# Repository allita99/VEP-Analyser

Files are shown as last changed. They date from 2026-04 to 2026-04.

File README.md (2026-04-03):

# VEP-Analyser-Motherboard

This repository contains an updated version of the hardware and software developed during my Bachelor's thesis, with incremental improvements and ongoing refinements.

The project integrates multiple components required for a VEP-based system, including firmware, sensor hardware, and the main motherboard design.

---

## Contents

* **Microcontroller Code**
  Firmware used for signal acquisition, control, and system interaction.

* **Motherboard Design**
  Central hardware platform responsible for system integration, power distribution, and communication between components.

* **VEP Sensor (VEPsor) Design**
  Hardware for acquiring visual evoked potential signals.

---

## Status

This repository reflects a working but evolving system:

* Several design and implementation improvements have been applied compared to the original thesis version
* Some components are still under development or require further validation
* Minor inconsistencies or unfinished elements may remain

---

## Purpose

The project is intended for:

* Research and experimentation in Brain-Computer Interfaces (BCI)
* Development and testing of VEP-based acquisition systems
* Educational use and hardware/software prototyping

---

## Notes

* Hardware designs may require verification before fabrication
* Firmware may need adaptation depending on the specific setup
* Some features are still work in progress and subject to change

---

Acknowledgement

Parts of the documentation and written content in this repository were generated with the assistance of AI tools. The text may be revised in the future if inaccuracies, inconsistencies, or improvements are identified.

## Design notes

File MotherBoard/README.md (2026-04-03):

# VEPsor – Motherboard Hardware

The **VEPsor Motherboard** is the central hardware component of the VEP Analyzer project. It functions as the primary interface between VEP sensor modules, processing units, and external systems, enabling reliable data acquisition and seamless system integration.

This repository contains all resources required to review, manufacture, and assemble the motherboard.

---

## Preview

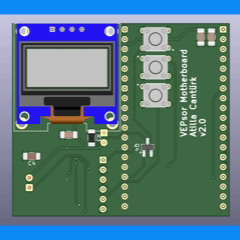
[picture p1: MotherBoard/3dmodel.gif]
3D Model


---

## Repository Contents

- **KiCad Project Files**  
  Complete schematic and PCB layout files for modification and extension.

- **Bill of Materials (BOM)**  
  Comprehensive list of components required for assembly.

- **Gerber Files**  
  Manufacturing-ready files for PCB fabrication.

- **schematics.pdf**  
  Exported schematic for quick inspection of the circuit design.

---

## Overview

The motherboard is designed to:

- Interface with VEP sensor modules  
- Provide stable power distribution across the system  
- Enable communication between hardware components  
- Serve as a reliable platform for BCI system integration  

### Key Design Goals

- Modular integration with sensor units  
- Robust signal routing and power management  
- Use of standard, widely available components  
- Expandability for future system extensions  

---

## Getting Started

### 1. Review the Design
- Open the KiCad project files for full access to the design  
- Use `schematics.pdf` for a quick overview  

### 2. PCB Fabrication
- Upload the Gerber files to a PCB manufacturer (e.g., JLCPCB, PCBWay)

### 3. Component Sourcing
- Use the BOM to procure all required components  

### 4. Assembly
- Assemble the board according to the PCB layout and schematic  
- Verify all power rails and connections before powering the system  

---

## Notes

- Ensure proper handling of power distribution sections  
- Follow ESD safety procedures during assembly  
- Validate voltage levels before connecting sensor modules  

---

## Intended Use

This hardware is intended for:

- Research and development in BCI systems  
- Integration of VEP-based sensing platforms  
- Experimental signal acquisition and processing setups  

This system is **not intended for medical or clinical use**.

---

## Feedback and Contributions

Feedback is encouraged. If you identify a bug, design issue, documentation error, or have suggestions for improvement, please open an Issue.

Constructive comments and contributions are welcome.

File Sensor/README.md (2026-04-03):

# VEPsor – VEP Sensor Hardware

**VEPsor (VEP Sensor)** is the hardware acquisition component of the VEP Analyzer project. It provides a compact and reproducible platform for capturing visual evoked potentials (VEPs) in Brain-Computer Interface (BCI) applications.

This repository contains all resources required to review, manufacture, and assemble the hardware.

---

## Preview

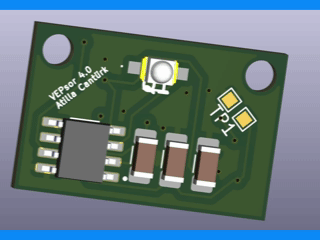
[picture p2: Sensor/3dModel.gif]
3D Model


---

## Repository Contents

- **KiCad Project Files**  
  Complete schematic and PCB design files for editing and modification.

- **Bill of Materials (BOM)**  
  Comprehensive list of components required for assembly.

- **Gerber Files**  
  Manufacturing-ready files for PCB fabrication.

- **schematics.pdf**  
  Exported schematic for quick inspection and validation of the circuit design.

---

## Overview

The VEPsor board is designed for:

- Acquisition of EEG signals related to visual stimuli  
- Integration into BCI systems  
- Rapid prototyping and experimental validation  

### Key Design Goals

- Reproducibility  
- Use of accessible, standard components  
- Compatibility with common EEG acquisition workflows  

---

## Getting Started

### 1. Review the Design
- Open the KiCad project files for full access to schematics and layout  
- Alternatively, inspect `schematics.pdf` for a quick overview  

### 2. PCB Fabrication
- Upload the Gerber files to a PCB manufacturer (e.g., JLCPCB, PCBWay)

### 3. Component Sourcing
- Use the BOM to order all required components  

### 4. Assembly
- Assemble the PCB according to the schematic and layout  
- Verify all connections before powering the board  

---

## Notes

- Handle analog and sensitive components with care  
- Follow ESD protection practices during assembly  
- Verify power supply requirements before operation  

---

## Intended Use

This hardware is intended for:

- Research and educational purposes  
- Experimental BCI systems  
- VEP signal acquisition and analysis  

This system is **not intended for medical or clinical use**.

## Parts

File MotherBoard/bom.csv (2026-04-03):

Designator | Footprint | Quantity | Value | LCSC Part #
C1, C10, C2, C3, C4, C5, C7 | 1206 | 7 | C_Small
C6 | 1206 | 1 | 1.5nC
C8 | 1206 | 1 | 0.22uC
D1 | LED_D5.0mm | 1 | LED
J2, J4 | PRT16766 | 2 | PRT-16766
J3 | PinHeader_1x06_P2.54mm_Vertical | 1 | Conn_01x06_Pin
LED1 | LED_D5.0mm | 1 | PT334-6C
Q4 | SOT-23_Handsoldering | 1 | NMOS
R10 | 1206 | 1 | 22kR
R11, R12 | 1206 | 2 | 220kR
R3 | 1206 | 1 | 250R
R8 | 1206 | 1 | 1MR
R9 | 1206 | 1 | 100kR
S1, S2, S3 | FSM4JH | 3 | FSM2JH
U1 | ESPRESSIF_ESP32-DEVKITC-32UE | 1 | ESP32-DEVKITC-32UE
U2 | MODULE_DM-OLED096-636 | 1 | DM-OLED096-636
U3 | SOIC127P600X175-8N | 1 | MCP6002-I_SN

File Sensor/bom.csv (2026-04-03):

Designator | Footprint | Quantity | Value | LCSC Part #
C1 | 1206 | 1 | 1.5nC
C2, C3 | 1206 | 2 | 0.22uC
D1 | SOD3716X135N | 1 | D_Schottky
J1 | SolderJumper-3_P1.3mm_Open_RoundedPad1.0x1.5mm_NumberLabels | 1 | Conn_01x03_Pin
J2 | PRT16766 | 1 | PRT-16766
Q1 | APDA3020P3CP22 | 1 | APDA3020P3C-P22
R1 | 1206 | 1 | 1MR
R2, R5 | 1206 | 2 | 220kR
R3 | 1206 | 1 | 22kR
R4 | 1206 | 1 | 100kR
TP1 | TestPoint_Pad_1.0x1.0mm | 1 | TH Testpoint
U2 | SOIC127P600X175-8N | 1 | MCP6002-I_SN

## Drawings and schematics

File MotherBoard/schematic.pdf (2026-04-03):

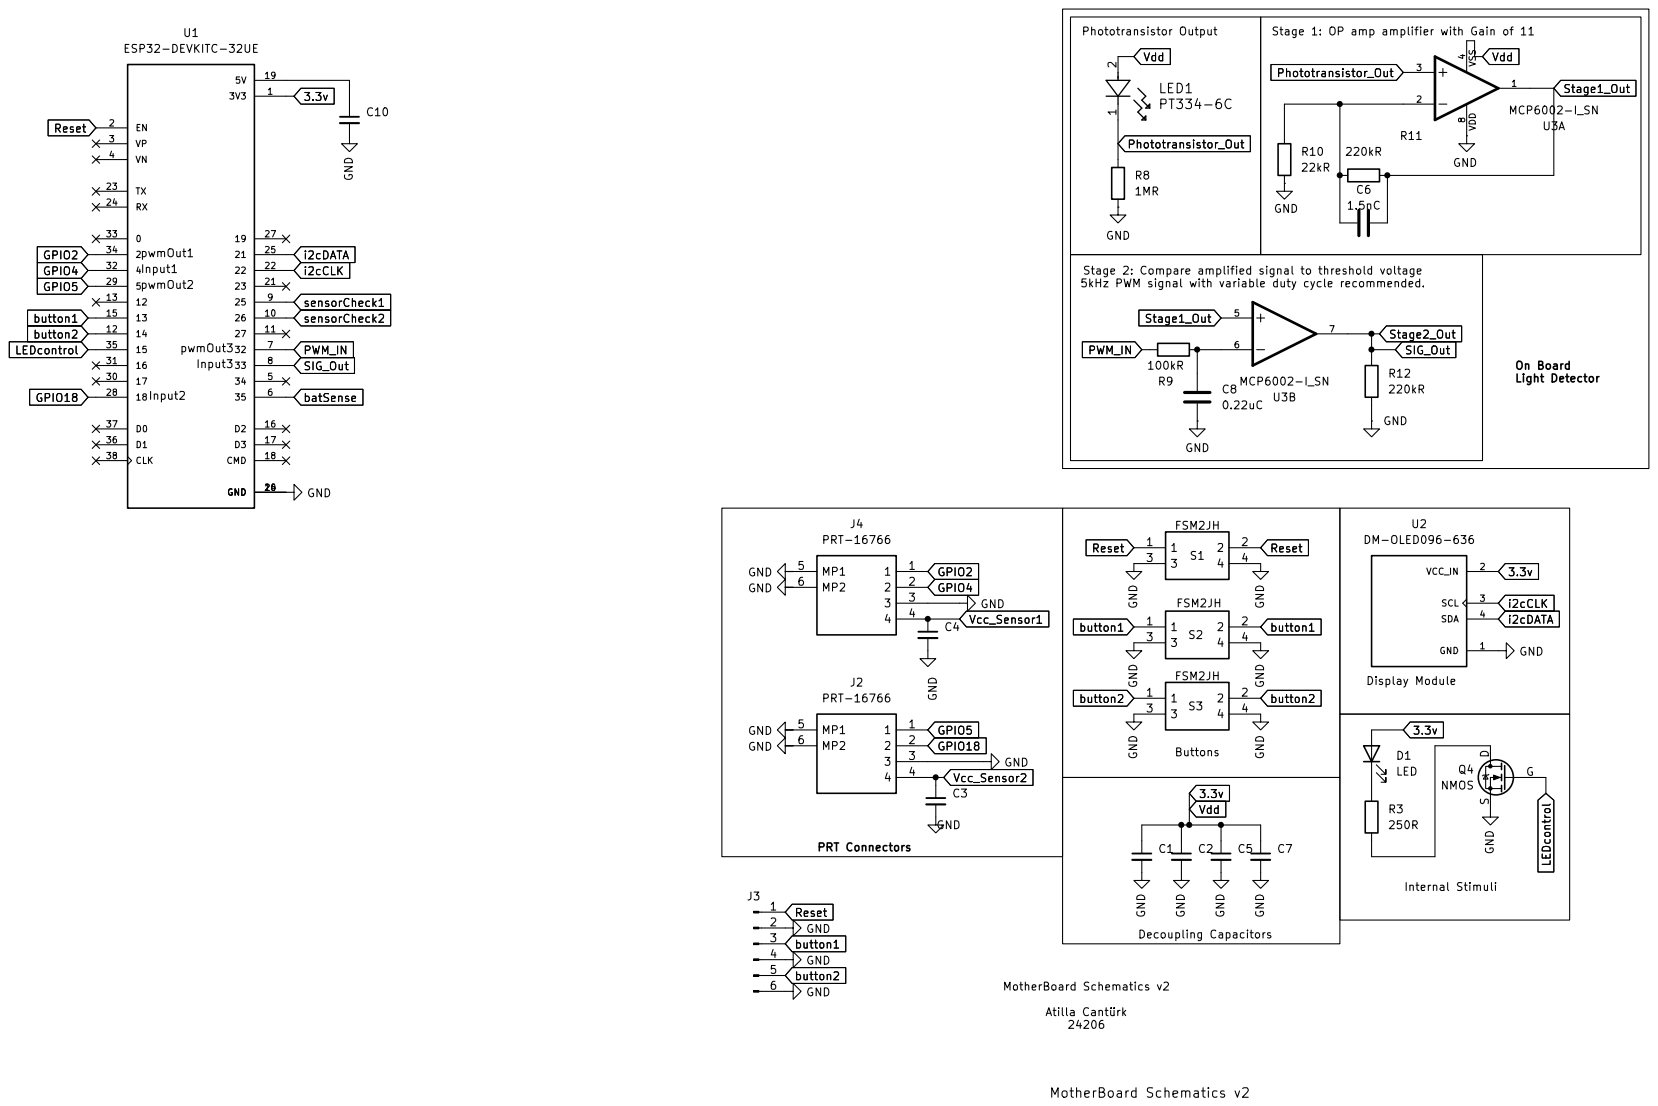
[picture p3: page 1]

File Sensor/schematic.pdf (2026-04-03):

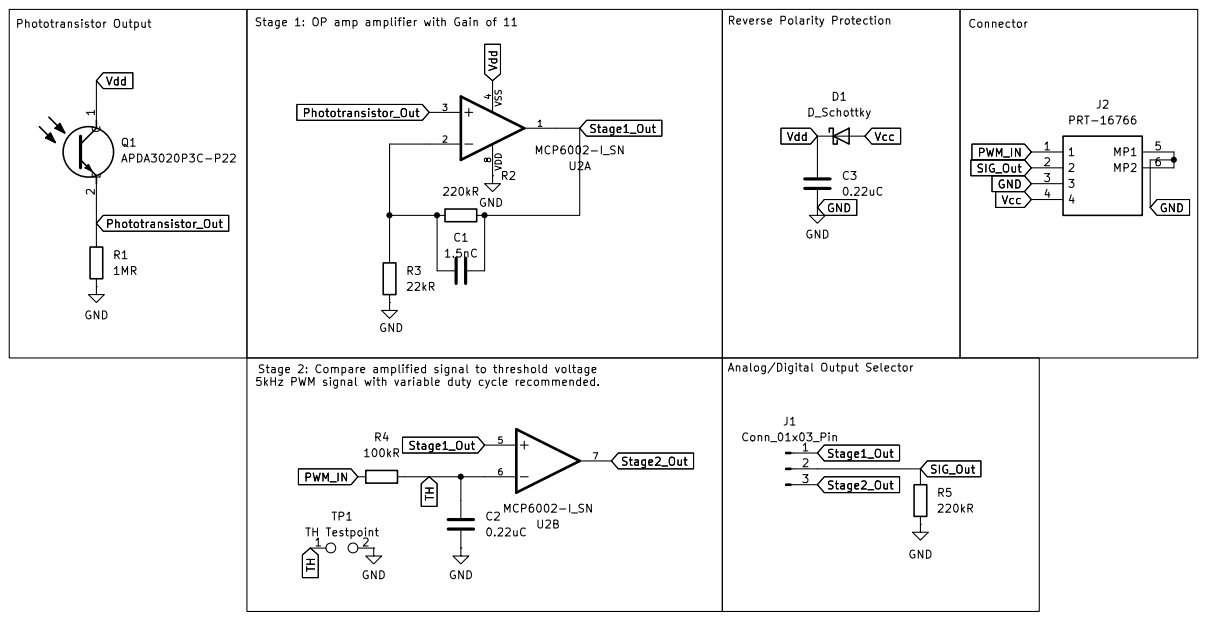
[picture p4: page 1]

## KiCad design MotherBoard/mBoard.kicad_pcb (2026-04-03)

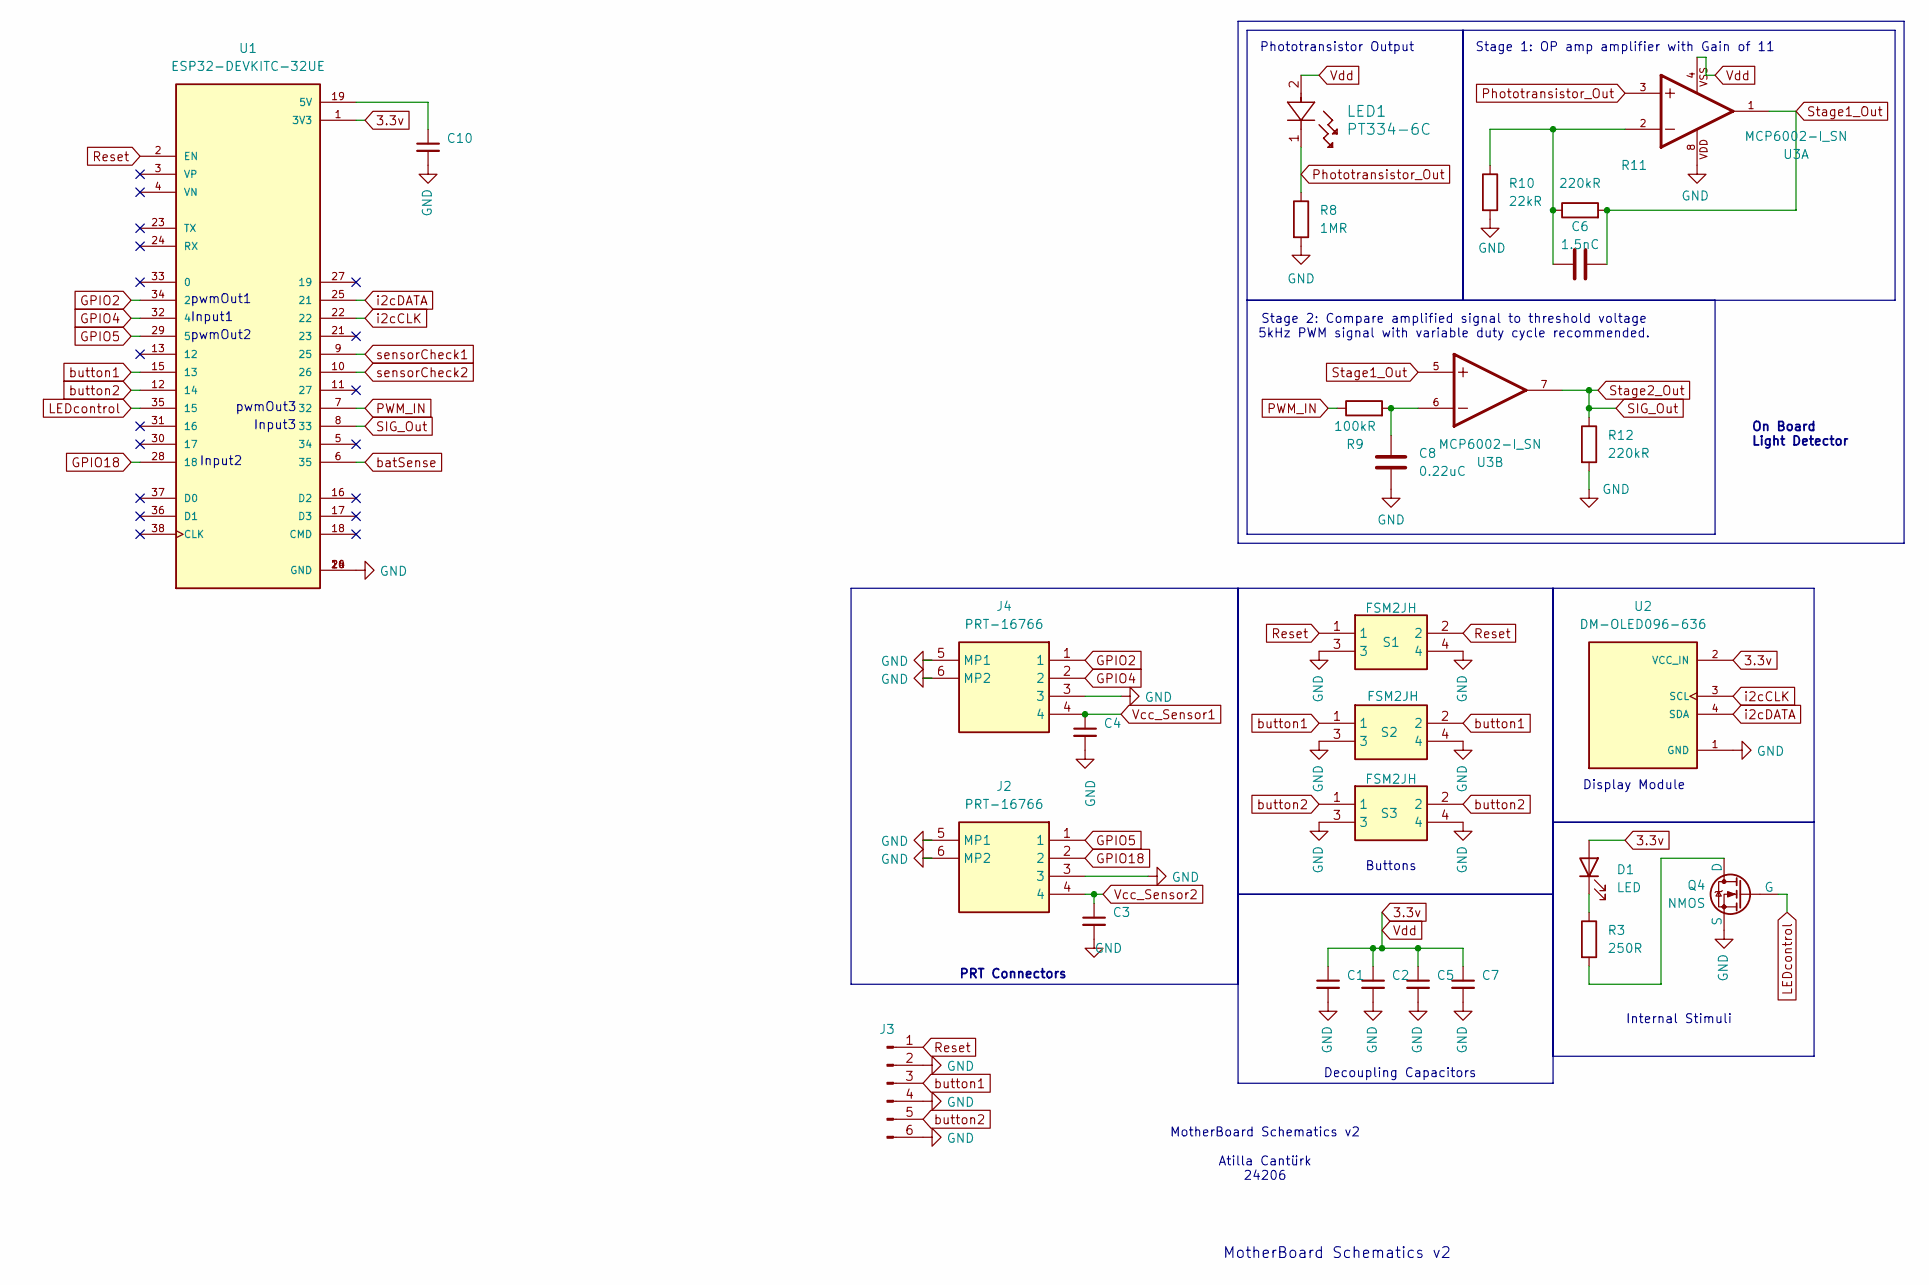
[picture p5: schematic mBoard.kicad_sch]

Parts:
C1, C2, C3, C4, C5, C7, C10: C_Small; C_1206_3216Metric_Pad1.33x1.80mm_HandSolder
C6: 1.5nC; C_1206_3216Metric_Pad1.33x1.80mm_HandSolder
C8: 0.22uC; C_1206_3216Metric_Pad1.33x1.80mm_HandSolder
D1: LED; LED_D5.0mm
J2, J4: PRT-16766; PRT16766; Mouser Part Number 474-PRT-16766
J3: Conn_01x06_Pin; PinHeader_1x06_P2.54mm_Vertical
LED1: PT334-6C; LED_D5.0mm
Q4: NMOS; SOT-23_Handsoldering
R3: 250R; R_1206_3216Metric_Pad1.30x1.75mm_HandSolder
R8: 1MR; R_1206_3216Metric_Pad1.30x1.75mm_HandSolder
R9: 100kR; R_1206_3216Metric_Pad1.30x1.75mm_HandSolder
R10: 22kR; R_1206_3216Metric_Pad1.30x1.75mm_HandSolder
R11, R12: 220kR; R_1206_3216Metric_Pad1.30x1.75mm_HandSolder
S1, S2, S3: FSM2JH; FSM4JH; Mouser Part Number 506-FSM2JH
U1: ESP32-DEVKITC-32UE; ESPRESSIF_ESP32-DEVKITC-32UE; PARTREV V4
U2: DM-OLED096-636; MODULE_DM-OLED096-636; PARTREV 2018-09-10
U3: MCP6002-I_SN; SOIC127P600X175-8N; PARTREV L

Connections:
3.3v: C1.1, C2.1, C5.1, C7.1, D1.2 (A), LED1.2, U1.1 (3V3), U2.2 (VCC_IN), U3.4
GND: C1.2, C2.2, C3.2, C4.2, C5.2, C7.2, C8.2, C10.2, J2.3, J2.5 (MP1), J2.6 (MP2), J3.2, J3.4, J3.6, J4.3, J4.5 (MP1), J4.6 (MP2), Q4.2 (S), R8.2, R10.2, R12.2, S1.3, S1.4, S2.3, S2.4, S3.3, S3.4, U1.14 (GND), U1.20 (GND), U1.26 (GND), U2.1 (GND), U3.8
GPIO2: J4.1, U1.34 (2)
GPIO4: J4.2, U1.32 (4)
GPIO5: J2.1, U1.29 (5)
GPIO18: J2.2, U1.28 (18)
LEDcontrol: Q4.1 (G), U1.35 (15)
unnamed: C6.1, R10.1, R11.1, U3.2
unnamed: C8.1, R9.2, U3.6
unnamed: D1.1 (K), R3.1
unnamed: Q4.3 (D), R3.2
unnamed: C10.1, U1.19 (5V)
PWM_IN: R9.1, U1.7 (32)
Phototransistor_Out: LED1.1, R8.1, U3.3
Reset: J3.1, S1.1, S1.2, U1.2 (EN)
SIG_Out: R12.1, U1.8 (33), U3.7
Stage1_Out: C6.2, R11.2, U3.1, U3.5
Vcc_Sensor1: C4.1, J4.4
Vcc_Sensor2: C3.1, J2.4
batSense: U1.6 (35)
button1: J3.3, S2.1, S2.2, U1.15 (13)
button2: J3.5, S3.1, S3.2, U1.12 (14)
i2cCLK: U1.22, U2.3 (SCL)
i2cDATA: U1.25 (21), U2.4 (SDA)
sensorCheck1: U1.9 (25)
sensorCheck2: U1.10 (26)

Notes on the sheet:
Input2
Phototransistor Output
Input1
Internal Stimuli
On Board Light Detector
pwmOut1
Display Module
Stage 2: Compare amplified signal to threshold voltage 5kHz PWM signal with variable duty cycle recommended.
pwmOut3
MotherBoard Schematics v2
Input3
Decoupling Capacitors
pwmOut2
MotherBoard Schematics v2 Atilla Cantürk 24206
Buttons
PRT Connectors
Stage 1: OP amp amplifier with Gain of 11

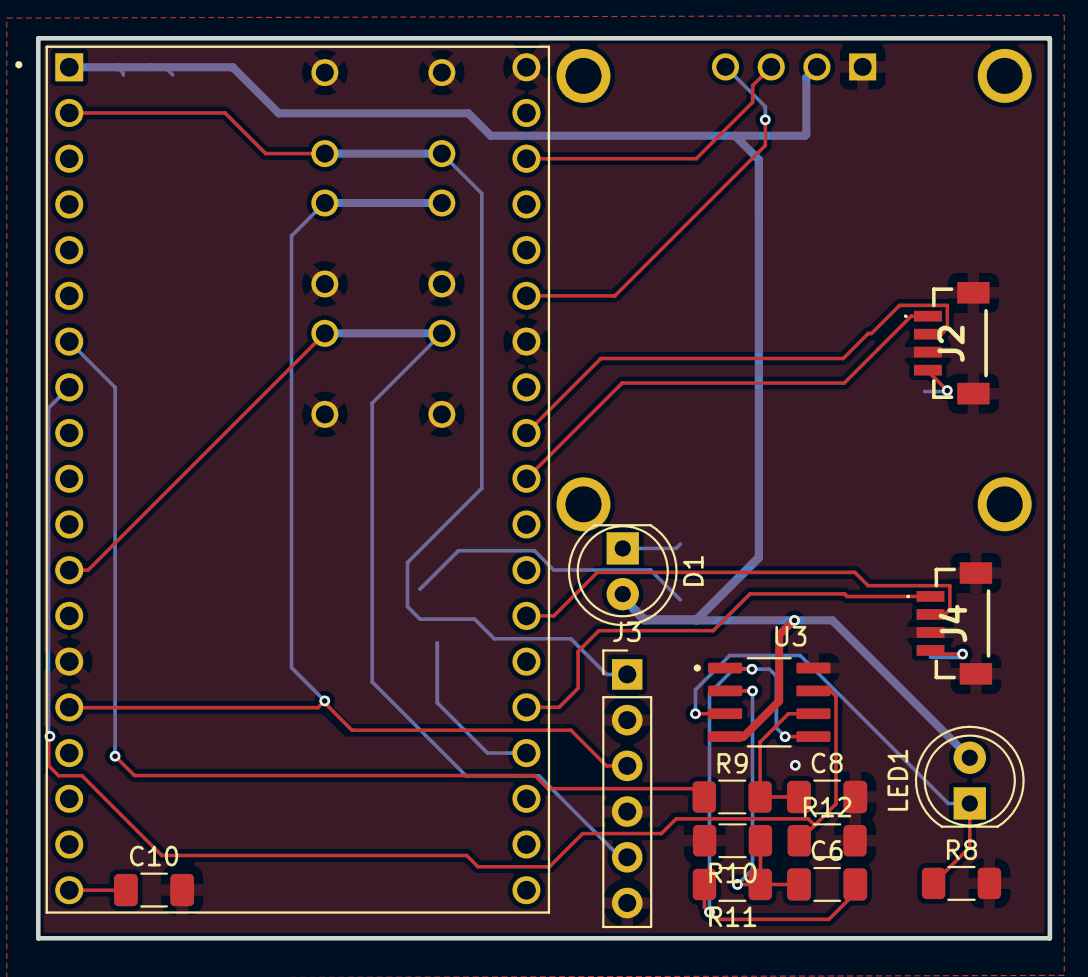
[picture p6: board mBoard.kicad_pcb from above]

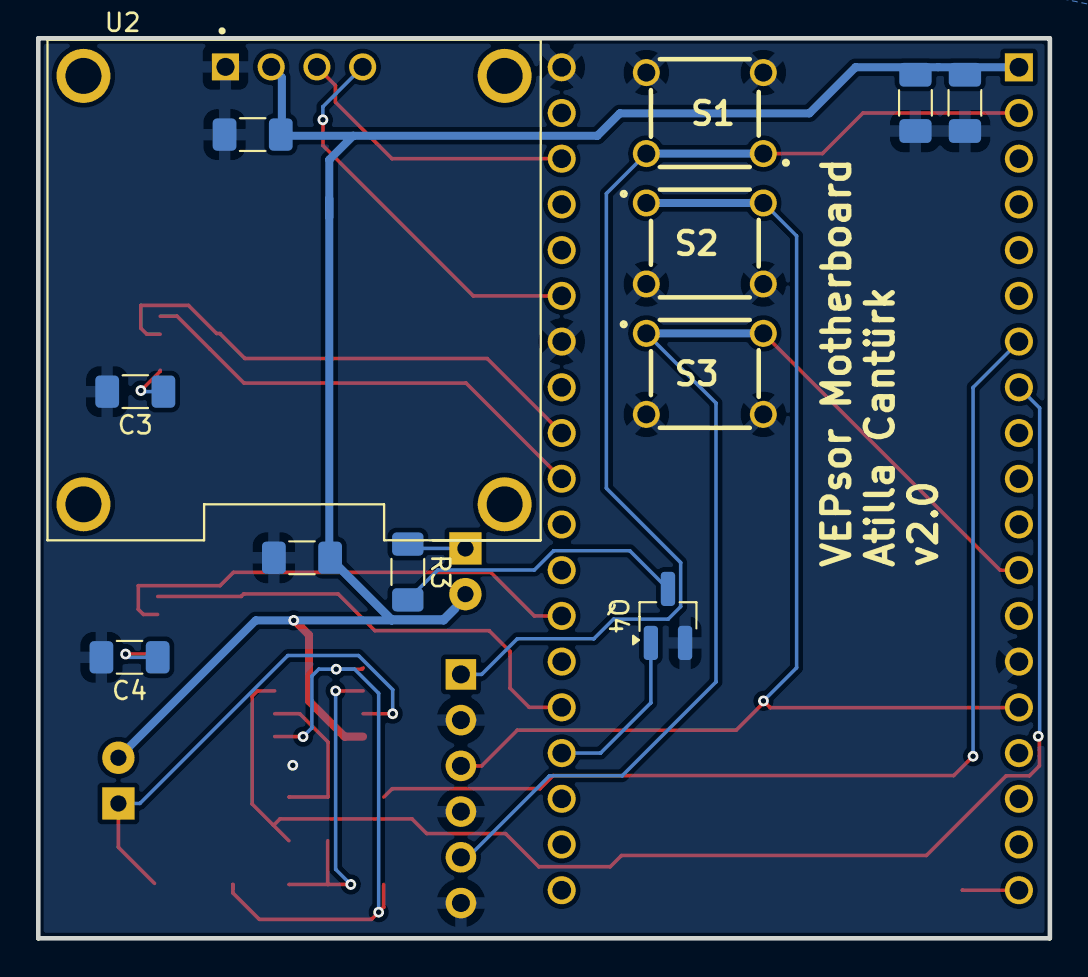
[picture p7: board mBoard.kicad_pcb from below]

Board: 2 copper layers, 56.2 x 50.0 mm, 27 parts (12 on the bottom side), 23 nets.

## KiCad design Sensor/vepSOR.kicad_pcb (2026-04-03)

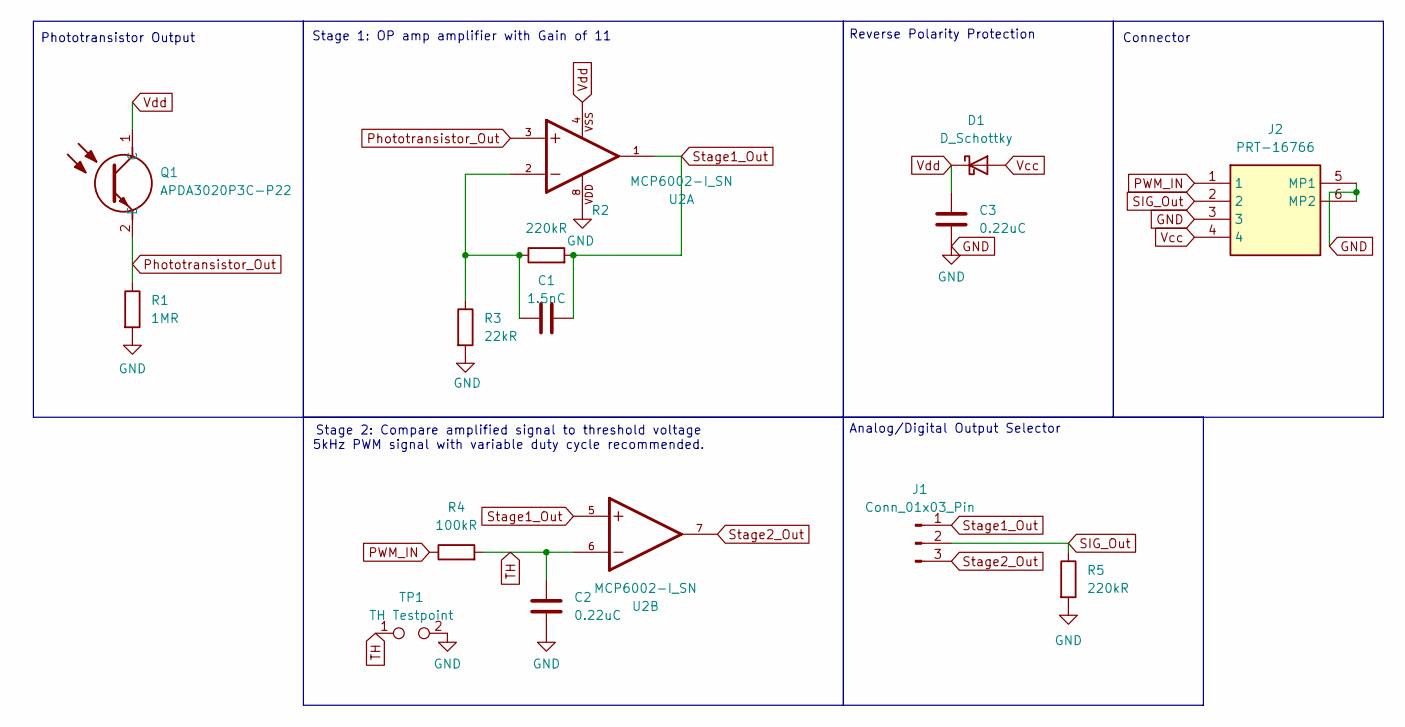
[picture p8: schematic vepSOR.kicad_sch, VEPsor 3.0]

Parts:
C1: 1.5nC; C_1206_3216Metric_Pad1.33x1.80mm_HandSolder
C2, C3: 0.22uC; C_1206_3216Metric_Pad1.33x1.80mm_HandSolder
D1: D_Schottky; SOD3716X135N
J1: Conn_01x03_Pin; SolderJumper-3_P1.3mm_Open_RoundedPad1.0x1.5mm_NumberLabels
J2: PRT-16766; PRT16766; Mouser Part Number 474-PRT-16766
Q1: APDA3020P3C-P22; APDA3020P3CP22; Manufacturer_Part_Number APDA3020P3C-P22
R1: 1MR; R_1206_3216Metric_Pad1.30x1.75mm_HandSolder
R2, R5: 220kR; R_1206_3216Metric_Pad1.30x1.75mm_HandSolder
R3: 22kR; R_1206_3216Metric_Pad1.30x1.75mm_HandSolder
R4: 100kR; R_1206_3216Metric_Pad1.30x1.75mm_HandSolder
TP1: TH Testpoint; TestPoint_Pad_1.0x1.0mm
U2: MCP6002-I_SN; SOIC127P600X175-8N; PARTREV L

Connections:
GND: C2.2, C3.2, J2.3, J2.5 (MP1), J2.6 (MP2), R1.2, R3.2, R5.2, TP1.2, U2.8
unnamed: C1.1, R2.1, R3.1, U2.2
PWM_IN: J2.1, R4.1
Phototransistor_Out: Q1.2 (E), R1.1, U2.3
SIG_Out: J1.2, J2.2, R5.1
Stage1_Out: C1.2, J1.1, R2.2, U2.1, U2.5
Stage2_Out: J1.3, U2.7
TH: C2.1, R4.2, TP1.1, U2.6
Vcc: D1.2 (A), J2.4
Vdd: C3.1, D1.1 (K), Q1.1 (C), U2.4

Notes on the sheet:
Reverse Polarity Protection
Analog/Digital Output Selector
Phototransistor Output
Stage 2: Compare amplified signal to threshold voltage 5kHz PWM signal with variable duty cycle recommended.
Connector
Stage 1: OP amp amplifier with Gain of 11

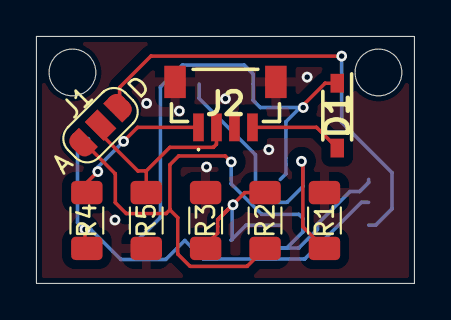
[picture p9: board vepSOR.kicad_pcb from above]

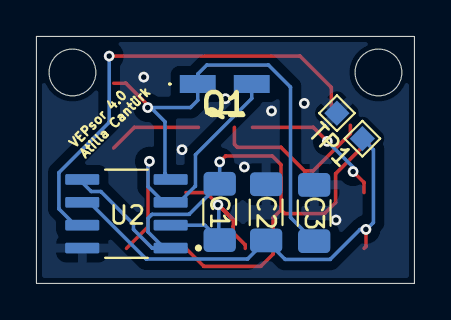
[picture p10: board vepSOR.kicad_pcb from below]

Board: 2 copper layers, 21.0 x 13.7 mm, 14 parts (6 on the bottom side), 10 nets.

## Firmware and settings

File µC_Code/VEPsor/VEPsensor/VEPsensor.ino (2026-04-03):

#include <Arduino.h>
#include "dataSampling.h"
#include "displayManager.h"
#include "vepSOR.h"
#include <esp_sleep.h>

#include <EEPROM.h>
#define EEPROM_SIZE 6 // define the number of bytes you want to access

#define SDA_1 21
#define SCL_1 22

//Pins for light detector
// SENSOR ONE
const int pwmChannel = 0;int pwmPin = 2;int inputPin = 4;int sensorCheck1 = 0;
int fixedDutyCycle = 124;int previousDutyCycle = 124;int dutyCycleCounter = 0;
int enSens = 25;
// SENSOR TWO
const int pwmChannel2 = 1;int pwmPin2 = 5;int inputPin2 = 18;int sensorCheck2 = 0;
int fixedDutyCycle2 = 124;int previousDutyCycle2 = 124;int dutyCycleCounter2 = 0;
int enSens2 = 26;
// SENSOR THREE
const int pwmChannel4 = 3; int pwmPin4 = 27; int inputPin3 = 19;
int fixedDutyCycle3 = 124;int previousDutyCycle3 = 124;int dutyCycleCounter3 = 0;

//LED OnBoard Stimuli
const int pwmChannel3 = 2;int pwmPin3 = 15;bool onBoardStimulusEnabled = false;
//Buttons
const int button1 = 13;const int button2 = 14;
const int batteryStatusCheck = 35;


bool startCommandReceived = false;bool calibrateCommandReceived = false;
bool startSavingCommandReveived = false;bool scanModecVEP = false; bool scanModeSSVEP = false;
unsigned long startTime = 0;
unsigned long previousMicros = 0;


// FOR RECORDING AND MANAGING SAVED DATA
const int duration = 10;      //seconds
const int sampleRate = 1000;  //1Khz
const int totalSamples = sampleRate * duration;
const int byteSize = 313;   //1,250 bytes for 10,000 samples
const int byteSize2 = 180;  //old 720  //1,250 bytes for 10,000 samples
const int bitSize = 10016;  //10000;
const int bitSize2 = 5760;  //5760;
uint32_t sensorData1[313];  //array that will keep the data from sensor1
uint32_t sensorData2[313];  //array that will keep the data from sensor2 might make it conditional (only declare if second sensor is connected in case of lack of memory)
uint32_t reData[180];
uint32_t reData2[180];
uint32_t memoryData[50];


uint32_t debounceTime = 400;  //250ms debounce protection
uint32_t lastButton1Press = 0;
uint32_t lastButton2Press = 0;
int previousButton1State = 0;
int previousButton2State = 0;

int currentSample = 0;  //current location
//bool dualSense = false;          // flag for dual sensor connection
//bool sensorSetupChange = false;
bool forceStop = false;
int pinValue = 0;   //
int pinValue2 = 0;  //
char buf[20];



const int freq = 5000;     // PWM Frequency in Hz
const int resolution = 8;  // Resolution in bits

int communicationSpeed = 1000;
uint32_t idleCounter = 0;
unsigned long lastIncrementTime = 0; 
unsigned long currentTime = millis();
const uint32_t idleThreshold = 120000;
bool isDeviceIdle = true;
int currentMode = 0;
int previousMode = 0;
bool isRecording = false;
String batteryStatus = "";
bool initialStart = true;

static double measuredFrequency = 0.0;
int recordedAmount = 0;
double freqArray[10] = {0.0, 0.0, 0.0, 0.0, 0.0, 0.0, 0.0, 0.0, 0.0, 0.0};
int freqArrayIndex = 0;
bool enableMemReload = true;
bool disableSensorCheck = true;
int totalModes = 5;

void wakeup_reason() {
  esp_sleep_wakeup_cause_t wakeup_reason = esp_sleep_get_wakeup_cause();

  if (wakeup_reason == ESP_SLEEP_WAKEUP_TIMER) {
    Serial.println("");
      Serial.println("Wakeup caused by timer. Reseting memory!");
      EEPROM.write(0, 0);EEPROM.write(1, 0);EEPROM.write(3, 0);
      EEPROM.write(4, 0);EEPROM.write(5, 0);EEPROM.commit();
      delay(10);
      esp_deep_sleep_start();}
  else{
    esp_sleep_enable_timer_wakeup(3600000000); // 1 hour = 3600 000 000 us  3600000000
  }
}

float standardDeviation(double array[], int recordCount){
  float allAdded = 0;
  float mean = 0;
  if(recordCount < 0){
     return 0.0;
  }
  else if(recordCount > 10){recordCount = 10;}
  //calculte mean
  for(int i = 0; i < recordCount; i++){allAdded = allAdded + array[i];}
  mean = allAdded / recordCount;allAdded = 0;
  //Calculate sigma part
  for(int j = 0; j < recordCount;j++){
      allAdded = allAdded + ((array[j]-mean) * (array[j]-mean));
  }
  return sqrt(allAdded / recordCount);
}

void resetSensorData(){
  for(int i = 0; i < 313; i++){
    sensorData1[i] = 0UL;
    sensorData2[i] = 0UL;
    if(i < 180)
      reData[i] = 0UL;
      reData2[i] = 0UL;
  }
}

float measureBattery() {
    const float upperVoltageLimit = 3.7;  // Fully charged voltage
    const float lowerVoltageLimit = 3.2;  // Empty voltage
    const float voltageDividerFactor = 2.0;  // Voltage divider factor
    const int adcResolution = 4095;  // ADC resolution for 12 bits
    const float V_ref = 3.3;  // Reference voltage for ADC

    int rawValue = analogRead(batteryStatusCheck);  // Read ADC value
    float V_measured = rawValue * (V_ref / adcResolution);  // Convert ADC value to measured voltage
    float V_battery = V_measured * voltageDividerFactor;  // Account for voltage divider

    if (V_battery <= lowerVoltageLimit) {
        return 0.0;  // Battery is empty
    } else if (V_battery >= upperVoltageLimit) {
        return 100.0;  // Battery is fully charged
    } else {
        return ((V_battery - lowerVoltageLimit) / (upperVoltageLimit - lowerVoltageLimit)) * 100.0;
    }
}

void setup() {

  Serial.begin(1000000);  //115200); 250000
  while (!Serial) { delay(10); }
  EEPROM.begin(EEPROM_SIZE);
  //Sensor 1 Setup
  ledcAttachChannel(pwmPin, freq, resolution, pwmChannel);
  pinMode(inputPin, INPUT_PULLDOWN);pinMode(enSens, INPUT_PULLDOWN);
  digitalWrite(enSens, LOW);
  //Sensor 2 Setup
  ledcAttachChannel(pwmPin2, freq, resolution, pwmChannel2); 
  pinMode(inputPin2, INPUT_PULLDOWN);pinMode(enSens2, INPUT_PULLDOWN);
  digitalWrite(enSens2, LOW);

  // Internal Stimuli at 20 Hz
  ledcAttachChannel(pwmPin3, 20, resolution, pwmChannel3); 

 
  //Button Setup, Button1 change mode button 2 toggle task
  pinMode(button1, INPUT_PULLUP);pinMode(button2, INPUT_PULLUP);

  wakeup_reason();//Checks wakup reason and sets timer or deep sleep mode

  // Retrieve previous states from memory 
  if(enableMemReload)
  {
  sensorCheck1 = EEPROM.read(2);
  sensorCheck2 = EEPROM.read(3);
  currentMode = EEPROM.read(4);

  if(sensorCheck1)
  {enableSensorPower(enSens);
  enableSensorPower(enSens2);
  ledcWrite(pwmPin, EEPROM.read(0));
  ledcWrite(pwmPin2, EEPROM.read(1)); //remember previous duty cycles  EEPROM.write(address, value);
  }
  if(sensorCheck2)
  {enableSensorPower(enSens);
  enableSensorPower(enSens2);
  ledcWrite(pwmPin, EEPROM.read(0));
  ledcWrite(pwmPin2, EEPROM.read(1));}
  }
  disableSensorPower(enSens);
  disableSensorPower(enSens2);

  initScreen();
  //bool ledcAttachChannel(uint8_t pin, uint32_t freq, uint8_t resolution, uint8_t channel);
  analogReadResolution(12);
  //resetDisplay();
  
  resetSensorData();
  //displayTwoLinesOfText(F("Main Menu"), batteryStatus);
}

void checkSerialCommands() {

  String command = Serial.readStringUntil('\n');
  if (command == "START" || command == "start") {
    currentSample = 0;  //reset location
    isDeviceIdle = false;
    startCommandReceived = true;
    calibrateCommandReceived = false;
    startSavingCommandReveived = false;
    isRecording = true;
    enableSensorPower(enSens);
    enableSensorPower(enSens2);
    //resetSensorData();
    // Serial.print(F("Duty cycle set to:"));
    // Serial.println(fixedDutyCycle);
    startTime = micros();  // Reset timer
    Serial.println(F("Start command received. Beginning data acquisition."));
    displayTwoLinesOfText(F("Beginned data acquisition!"), F(""));
    //ledcWrite(pwmPin, fixedDutyCycle);
    //delay(500);
  } else if (command == "STOP" || command == "stop" || forceStop) {
    startCommandReceived = false;
    calibrateCommandReceived = false;
    startSavingCommandReveived = false;
    disableSensorPower(enSens);
    disableSensorPower(enSens2);
    isRecording = false;
    forceStop = false;
    scanModecVEP = false;
    scanModeSSVEP = false;
    Serial.println(F("Stop command received. Halting data acquisition."));
    displayTwoLinesOfText(F("Halted data acquisition!"), F(""));

    unsigned long startTime = millis();  // Record start time
    uint8_t tapPoint = 0;
    uint8_t detectedPolynomial = 0;
    // Perform the calculations
    for (int i = 0; i < 48; i++) {
      //Serial.print(24+i);
      downSample32(sensorData1, reData, byteSize, 24 + i);  // Downsample data
      tapPoint = compareSequences32(reData, (24 + i) * 10, 30);
      if (tapPoint != 0b00000000)    // Compare sequences
      {
        Serial.println("Sensor1: ");
        Serial.print(24 + i);
        Serial.println("");
        Serial.println(getPolynomial(tapPoint));
        if((detectedPolynomial != tapPoint) && (detectedPolynomial == 0)){
            detectedPolynomial = tapPoint;
        }
        if((detectedPolynomial == tapPoint) && (detectedPolynomial != 0)){
           detectedPolynomial = tapPoint;
        }
      }
      
    }

    unsigned long elapsedTime = millis() - startTime;  // Calculate elapsed time

    // Print the elapsed time
    Serial.print(F("Calculation Time: "));
    Serial.print(elapsedTime);
    Serial.println(F(" ms"));

    // TEST TODO
    isDeviceIdle = true;
    
  } else if (command == "CALIBRATE" || command == "cal") {
  enableSensorPower(enSens);
    enableSensorPower(enSens2);
    Serial.println(F("Calibration command received."));
        currentMode = 0;
        startCommandReceived = false;
        startSavingCommandReveived = false;
        calibrateCommandReceived = true;
        scanModecVEP = false;
        scanModeSSVEP = false;
        isDeviceIdle = false;
        fixedDutyCycle = 0b10000000;
        fixedDutyCycle2 = 0b10000000;
        ledcWrite(pwmPin, fixedDutyCycle);
        ledcWrite(pwmPin2, fixedDutyCycle2);
        Serial.println(F("Duty Cycle Reset!"));
        isDeviceIdle = true;

  } else if (command == "DUTY" || command == "duty") {
    startCommandReceived = false;
    calibrateCommandReceived = false;
    startSavingCommandReveived = false;
    isDeviceIdle = false;
    Serial.println(F("Enter the duty cycle value (0-255):"));
    unsigned long startTime = millis();
    const unsigned long timeout = 5000;  // 5 seconds timeout

    while (Serial.available() == 0) {
      if (millis() - startTime > timeout) {
        Serial.println(F("Timeout: No input received."));
        return;  // Exit the function if no input is received within the timeout period
      }
      // Elevator Music
    }
    int dCycle = Serial.parseInt();
    fixedDutyCycle = dCycle;
    ledcWrite(pwmPin, dCycle);
    //delay(500);
    Serial.print(F("Duty cycle set to: "));
    Serial.println(ledcRead(pwmPin));
    isDeviceIdle = true;
  } else if (command == "SPEED" || command == "speed") {
    startCommandReceived = false;
    startSavingCommandReveived = false;
    calibrateCommandReceived = false;
    isDeviceIdle = false;
    Serial.println(F("Enter the sampling period (us):"));
    unsigned long startTime = millis();
    const unsigned long timeout = 5000;  // 5 seconds timeout

    while (Serial.available() == 0) {
      if (millis() - startTime > timeout) {
        Serial.println(F("Timeout: No input received."));
        return;  // Exit the function if no input is received within the timeout period
      }
      // Elevator Music
    }

    int speed = Serial.parseInt();
    if (speed >= 500) {
      communicationSpeed = speed;
    } else {
      communicationSpeed = 1000;  //default value
    }
    //delay(500);  // delay bad
    Serial.print(F("Sampling period set to (us): "));
    Serial.println(speed);
    isDeviceIdle = true;
  }
}
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
void loop() {
  if (Serial.available() > 0) {
    checkSerialCommands();  // function dealing with terminal commands from pc just for simplifying the main.
    idleCounter = 0;
  }

  if(initialStart){
    delay(350);
    batteryStatus =  "Bat: " + String(measureBattery()) + " %";
    //displayTwoLinesOfText(F("Main Menu"), batteryStatus);
    switch (currentMode) {
      case 0:
        batteryStatus =  "Bat: " + String(measureBattery()) + " %";
        Serial.println(F("Mode: Main Menu"));
        displayTwoLinesOfText(F("Main Menu"), batteryStatus);
        break;
      // case 1:
      //   Serial.println(F("Mode: Calibration"));
      //   displayTwoLinesOfText(F("Calibration Mode"), F(""));
      //   break;
      case 3:
        Serial.println(F("Stream Mode: Start/Stop"));
        displayTwoLinesOfText(F("Start/Stop Mode"),  F("Data Stream"));
        break;
      case 1:
        Serial.println(F("SSVEP Mode: Start/Stop"));
        displayTwoLinesOfText(F("Start/Stop Mode"), F("Find frequency."));
        break;
      case 2:
        Serial.println(F("cVEP Mode: Start/Stop "));
        displayTwoLinesOfText(F("Start/Stop Mode"), F("Find polynomial of\nthe m-sequence."));
        break;
      case 4:
        Serial.println(F("Mode: Internal Stimuli"));
        //displayThreeLinesOfText(F("Toggle"), F("On board light stimulus."),"");
        if(onBoardStimulusEnabled)
          displayThreeLinesOfText(F("Toggle"), F("Internal Stimuli"),"On");
        else
          displayThreeLinesOfText(F("Toggle"), F("Internal Stimuli"),"Off");
        break;
    }
    initialStart = false;

    Serial.println("");
    Serial.println(EEPROM.read(0));
    Serial.println(EEPROM.read(1));
    Serial.println(EEPROM.read(2));
    Serial.println(EEPROM.read(3));
    Serial.println(EEPROM.read(4));
  }
  checkButtonCommands();
 
  //Data loop
  // Data loop
  if (startCommandReceived) {
        unsigned long currentMicros = micros();
        unsigned long elapsedTime = currentMicros - startTime; // Calculate elapsed time

      
        if (scanModecVEP && elapsedTime >= 10500000UL) {  //CVEP analysis termination
          Serial.println(F("cVEP mode: Scanning complete after 10.5 seconds."));
          startCommandReceived = false; // Stop scanning
          stopAndAnalyseCVEP();
          //return;
        }

        
        if (scanModeSSVEP) { // SSVEP analysis simple frequency analysis
          static unsigned long lastEdgeTime = 0;
          
          // On each loop iteration:
          int currentPinValue;

          if (sensorCheck2 && !sensorCheck1)
            currentPinValue = digitalRead(inputPin2); 
          else
            currentPinValue = digitalRead(inputPin);

          // Rising edge detection
          static int prevPinValue = LOW;
          if (currentPinValue == HIGH && prevPinValue == LOW) {
              unsigned long thisEdgeTime = micros();
              if (lastEdgeTime != 0 && (thisEdgeTime > lastEdgeTime)) {
                unsigned long edgeDelta = thisEdgeTime - lastEdgeTime;// how much time passed
                double frequency = 0;
                
                if((1000000.0 / (double)edgeDelta) <= communicationSpeed/2) // ignore frequencies higher than half the sampling frequency
                  frequency = 1000000.0 / (double)edgeDelta;
                else
                  frequency = measuredFrequency;

                
                // Optimized EWMA
                //measuredFrequency = (frequency + 15.0 * measuredFrequency + 0.5) / 16.0;
                //measuredFrequency = 0.2 * ( 2 * measuredFrequency + 4 * frequency);  // simple weighted average filter for more stable output
                measuredFrequency = 0.8 * measuredFrequency + 0.2 * frequency;
                //measuredFrequency = frequency;
               
                

              }
              lastEdgeTime = thisEdgeTime;
          }
          prevPinValue = currentPinValue;

          static unsigned long lastPrintTime = 0;
          unsigned long now = millis();
          if (now - lastPrintTime > 500) {   // Print every half-second
              Serial.print(F("Frequency Detected: "));
              Serial.print(measuredFrequency, 4);
              Serial.print(F(" Hz "));
              Serial.print(F("+-"));
              Serial.println(standardDeviation(freqArray, recordedAmount),4);
              freqArray[freqArrayIndex] = measuredFrequency;
              freqArrayIndex = (freqArrayIndex + 1) % 10; // loop between 0-9 
              if(recordedAmount < 10)
              {
                recordedAmount++;
              }
              //displayTwoLinesOfText("Frequency analysis:", "\nf= " + String(measuredFrequency, 4) + " Hz");
              displayThreeLinesOfText("Frequency analysis:", "f= " + String(measuredFrequency, 4) + " Hz" , "+-" + String(standardDeviation(freqArray, recordedAmount),4) + " ||");
              lastPrintTime = now;
          }
        }


    if ((sensorCheck1 != 0) && (sensorCheck2 != 0)) { // Dual sensors detected
      pinValue = digitalRead(inputPin);
      pinValue2 = digitalRead(inputPin2);
      forceStop = false;
    } else if ((sensorCheck1 == 0) && (sensorCheck2 != 0)) { // Only sensor 2 detected
      pinValue = digitalRead(inputPin2);
      pinValue2 = 0;
      forceStop = false;
    } else if ((sensorCheck1 != 0) && (sensorCheck2 == 0)) { // Only sensor 1 detected
      pinValue = digitalRead(inputPin);
      pinValue2 = 0;
      forceStop = false;
    } else { // Nothing detected
      Serial.println(F("No sensor detected."));
      pinValue = 0;
      pinValue2 = 0;
      forceStop = true;
      return;
    }

    if (currentMicros - previousMicros >= communicationSpeed) {
      previousMicros = currentMicros;
      unsigned long timestamp = currentMicros - startTime;
      if(!scanModeSSVEP && !scanModecVEP)
      {Serial.print(timestamp, HEX);  // Print timestamp
      Serial.print(F(","));}
      
      // Print sensor data
      if ((sensorCheck1 != 0) && (sensorCheck2 != 0)) { // Dual sensors
        if(!scanModeSSVEP && !scanModecVEP) {
          Serial.print(pinValue);
          Serial.print(F(","));
          Serial.println(pinValue2);}
        if (currentSample < 10016) {
          setBit32(sensorData1, currentSample, pinValue);
          setBit32(sensorData2, currentSample, pinValue2);
          currentSample++;
        }
      } else { // Single sensor
        
        if(!scanModeSSVEP && !scanModecVEP)
          Serial.println(pinValue);
        if (currentSample < 10016) {
          setBit32(sensorData1, currentSample, pinValue);
          currentSample++;
        }
      }
    }
  }


  if (calibrateCommandReceived) {
    isDeviceIdle = false;
    enableSensorPower(enSens);
    enableSensorPower(enSens2);
    displayTwoLinesOfText(F("Calibrating..."), F(""));
    if(testSensorConnection(pwmPin, inputPin, fixedDutyCycle, sensorCheck1) > 0) //test for basic sensor outputs
      {fixedDutyCycle = calibrateSensor(pwmPin, inputPin, fixedDutyCycle, sensorCheck1 );  //calibrate();
      EEPROM.write(0, fixedDutyCycle);
      EEPROM.write(2, 1);
      } // save sensor1 state
    else{
      EEPROM.write(0, 0); // save sensor1 state
      EEPROM.write(2, 0);
      disableSensorPower(enSens);
      disableSensorPower(enSens2);
    }
    
    if(testSensorConnection(pwmPin2, inputPin2, fixedDutyCycle2, sensorCheck2) > 0)  //test for basic sensor outputs
      {fixedDutyCycle2 = calibrateSensor(pwmPin2, inputPin2, fixedDutyCycle2, sensorCheck2);
      EEPROM.write(1, fixedDutyCycle2);
      EEPROM.write(3, 1);
      } // save sensor2 state
    else{
      EEPROM.write(1, 0); // save sensor2 state
      EEPROM.write(3, 0);
      disableSensorPower(enSens);
      disableSensorPower(enSens2);
    }

    char line1[32], line2[32];
    if(sensorCheck1 > 0)
      sprintf(line1, "Sensor 1: %d", fixedDutyCycle);
    else
      sprintf(line1, "Sensor 1: ---");
    if(sensorCheck2 > 0)
      sprintf(line2, "Sensor 2: %d", fixedDutyCycle2);
    else
       sprintf(line2, "Sensor 2: ---");
    displayTwoLinesOfText(line1, line2);
    calibrateCommandReceived = false;
    isDeviceIdle = true;
    idleCounter = 0;
    EEPROM.commit();// push changes to memory
  }
  
  if (isDeviceIdle) { //IDLE COUNTER LOOP
    currentTime = millis();
    if (currentTime - lastIncrementTime >= 1) { // If one millisecond has passed update counter
      idleCounter = idleCounter + 1;
      lastIncrementTime = currentTime;
      //Serial.println(idleCounter);
    }
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

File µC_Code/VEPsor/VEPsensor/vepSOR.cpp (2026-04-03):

#include "vepSOR.h"


int calibrateSensor(int& pwm, int& input, int& dCycle, int& sensorStatus) {
    int adjustmentValue = 128 / 2; // added or subtracted from duty cycle
    unsigned long loopDuration = 1500; // 1.5-second main loop
    unsigned int changeCounter = 0;
    unsigned int scanInterval = 1;
    float peakCounter = 0;
    dCycle = 0b10000000; // Middle value
    bool ableToDetectChanges = false;
    unsigned long currentTime;
    unsigned long prevTime = 0;
    sensorStatus = 0;
    dutyCycleCounter = 0;
    ledcWrite(pwm, dCycle);
    int pinValue = digitalRead(input);
    int prevPinValue = pinValue;

    while (!ableToDetectChanges) {
        unsigned long delayStartTime = millis();
        while (millis() - delayStartTime < 150) {
            // elevator music (wait for capacitor to charge)
        }
        startTime = millis();
        while (millis() - startTime < loopDuration) {
            currentTime = millis();
            if (currentTime - prevTime >= scanInterval) {
                prevTime = currentTime;
                pinValue = digitalRead(input);
                if (pinValue) {peakCounter++;} else {peakCounter--;}

                if (pinValue != prevPinValue) {
                    changeCounter++;
                    prevPinValue = pinValue;
                }
            }
        }

        if (changeCounter > 5) {
            ableToDetectChanges = true;
            Serial.println("Calibration complete.");
            Serial.println(dCycle);
            sensorStatus = 1; 
            calibrateCommandReceived = false;
            return dCycle;
        } else {
            if (peakCounter >= 5) {
                dCycle += adjustmentValue;
                adjustmentValue /= 2;
                Serial.print(">: ");
                Serial.println(ledcRead(pwm));
                sensorStatus = 0;
            } else if (peakCounter <= -5) {
                dCycle -= adjustmentValue;
                adjustmentValue /= 2;
                Serial.print("<: ");
                Serial.println(ledcRead(pwm));
                sensorStatus = 0;
            }

            if (dutyCycleCounter >= 3) {
                calibrateCommandReceived = false;
                Serial.println("Calibration failed.");
                sensorStatus = 0;
                return dCycle;
            }

            changeCounter = 0;
            ledcWrite(pwm, dCycle);
            if (previousDutyCycle == dCycle) {
                dutyCycleCounter++;
            }
            previousDutyCycle = dCycle;
        }
    }

    sensorStatus = 0;
    calibrateCommandReceived = false;
    return dCycle;
}


int calibrate() { 
  // INITIAL PARAMETERS
  int adjustmentValue = 128 / 2; // added or substracted from d_cycle
  unsigned long loopDuration = 1500; // 1.5 second main loops
  unsigned int changeCounter = 0;
  unsigned int scanInterval = 1;
  float peakCounter = 0;
  fixedDutyCycle = 0b10000000; // Set threshold to middle value (128 or half the reference voltage) 
  bool ableToDetectChanges = false;
  unsigned long currentTime;
  unsigned long prevTime = 0; 

  dutyCycleCounter = 0;
  ledcWrite(pwmPin, fixedDutyCycle);
  int pinValue = digitalRead(inputPin);
  int prevPinValue = digitalRead(inputPin);

  while (!ableToDetectChanges) {
    unsigned long delayStartTime = millis();
    Serial.println("wait 300");
    while (millis() - delayStartTime < 300) {
        //Elevator music
      }
    Serial.println("start timer");
    startTime = millis(); // Reset timer
    Serial.print("wait ");
    Serial.println(loopDuration);
    while (millis() - startTime < loopDuration) { // Test the sensor for 1.5 seconds
      currentTime = millis();
      if (currentTime - prevTime >= scanInterval) { // Read Digital input once every 1ms
        prevTime = currentTime;

        pinValue = digitalRead(inputPin);
        if (pinValue) {
          peakCounter++;
        } else {
          peakCounter--;
        }
        if (pinValue != prevPinValue) {
          changeCounter++; // Count changes
          prevPinValue = pinValue; // Update the previous value
        }
      }
    }

    if (changeCounter > 5) { // more than 4 changes detected
      ableToDetectChanges = true;
      Serial.println("Calibration complete.");
      Serial.println(fixedDutyCycle);
      calibrateCommandReceived = false;
      return fixedDutyCycle;
    } else {
      if (peakCounter >= 5) {  
        fixedDutyCycle = fixedDutyCycle + adjustmentValue; // Increase by current adjustment
        adjustmentValue = adjustmentValue / 2; // Halve the adjustment for next iteration
        peakCounter = 0;
        Serial.print(">: ");
        Serial.println(ledcRead(pwmPin));
    } else if (peakCounter <= -5) {
        fixedDutyCycle = fixedDutyCycle - adjustmentValue; // Decrease by current adjustment
        adjustmentValue = adjustmentValue / 2; // Halve the adjustment for next iteration
        peakCounter = 0;
        Serial.print("<: ");
        Serial.println(ledcRead(pwmPin));
    } 
      if(dutyCycleCounter >= 3){
        calibrateCommandReceived = false;
        
        Serial.println("Calibration failed.");
        Serial.println(ledcRead(pwmPin));
        return fixedDutyCycle;
      }
      changeCounter = 0; // Reset Counter
      ledcWrite(pwmPin, fixedDutyCycle);
      if(previousDutyCycle == fixedDutyCycle){
          dutyCycleCounter++;
      }
      previousDutyCycle = fixedDutyCycle;
    }
    
  }
  calibrateCommandReceived = false;
  return fixedDutyCycle;
}

void enableSensorPower(int& sensorControlPin){
   digitalWrite(sensorControlPin, HIGH);
   //return 0;
}
void disableSensorPower(int& sensorControlPin){
  digitalWrite(sensorControlPin, LOW);
  //return 0;
}
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
